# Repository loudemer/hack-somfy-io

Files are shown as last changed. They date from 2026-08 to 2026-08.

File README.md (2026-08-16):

# Hack télécommande Somfy pure IO

## Introduction
Home Assistant ne permet pas d'émuler les télécommandes Somfy IO. La solution est de passer par des boitiers Somfy type Tahoma, connexonn io ou équivalents qui représentent un budget non négligeable mais qui restent la meilleure solution lorsque l'on a plusieurs appareils Somfy car ils permettent en outre de récupérer l'état réel de chaque appareil. 
Lorsque l'on a un ou deux appareils Somfy IO et le reste en RTS comme moi, il devient interessant de hacker une telecommande Somfy IO pour la rendre pilotable par Home Assistant, ceci avec un faible budget mais à condition de savoir souder. 
Il existe déjà des [montages sur Youtube](https://www.youtube.com/watch?v=AbRFvk2iZs8&t=708s) qui expliquent comment faire. Le montage que je propose est dérivé de celui ci avec quelques améliorations sur un modèle de télécommande plus récent : Somfy Situo 1 Pure IO.

## Principe
La télécommande possède 3 boutons pour envoyer les 3 signaux : UP, MY, DOWN. Sur le circuit imprimé de la técommande, chaque bouton se présente sous forme d'un cercle entouré d'un anneau. l'appui sur un bouton met en contact le cercle et l'anneau, ce qui correspond à une mise à la masse de l'anneau. Ce dernier est normalement à 3,3v.

Il faut donc simplement mettre a la masse un des 3 anneaux pour déclencher une des commandes (UP,MY, DOWN). On peut le faire de plusieurs manières soit avec des relais commandés par HA ou plus simplement avec un circuit de type ESP32 ou Wemo D1 programmé avec ESPHome. C'est la solution proposée dans la vidéo citée précedemment qui utilise un ESP32. L'auteur a soudé un fil sur chacun des trois anneaux relié à 3 sorties GPIO de l'ESP32 et cela marche très bien. On effectue alors la commande à partir de HA.

Etant prudent, je voulais pouvoir toujours utiliser la télécommande au cas où il y aurait une panne sur HA. J'ai donc cherché les points correspondants aux 3 anneaux sur l'autre face du circuit imprimé pour y souder les 3 fils de commande et pouvoir ainsi garder les boutons de la télécommande opérationnels.
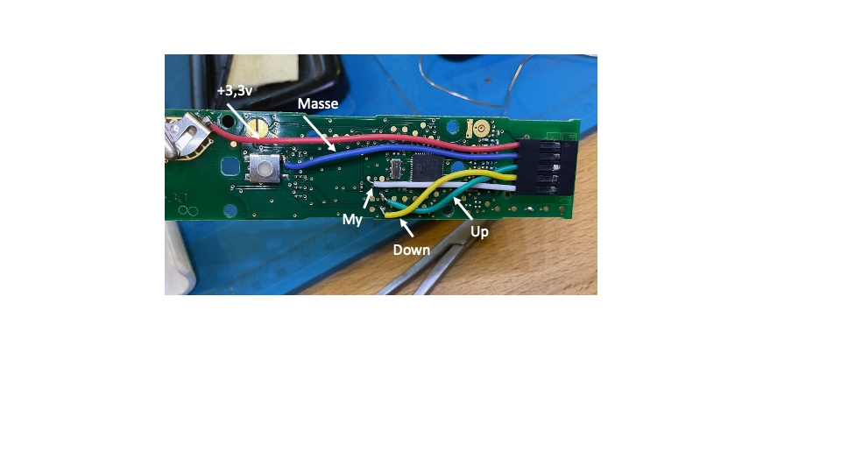
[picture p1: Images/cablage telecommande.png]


J'ai utilisé un Wemo D1 pour la commande, c'est largement suffisant. 

Il y a alors 2 problèmes à résoudre :
 1. lorsqu'on utilise les boutons de la télécommande, on met a la masse l'output du GPIO du Wemo, ce qui peut l'endommager. Il faut donc isoler la sortie du wemo en interposant un transistor selon le schéma suivant (une diode ne fonctionne pas).
 2. HA doit être informé de l'appui du bouton lorsqu'on utilise la télécommande, donc il faut renvoyer l'information sur 3 GPIO du wemo configurés en Input.

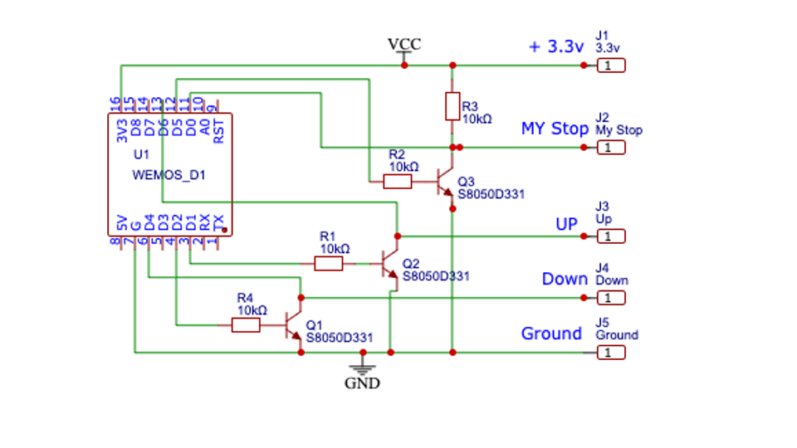
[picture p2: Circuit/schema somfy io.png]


L'alimentation de la télécommande se fait par le Wemo car la consommation est très basse. Il ne faut donc pas de pile dans la télécommande.

## Réalisation
Le montage du wemo et de son interface avec les transistors se fait au mieux sur un circuit imprimé. Un PCB est fourni en exemple pour sa réalisation. (format pdf dans le dossier PCB)
Les composants sont :
1. 3 transistors NPN S8050 ou BC547
2. 4 résistances 1/4 w 10K
3. 1 wemo D1

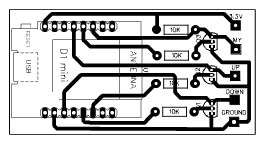
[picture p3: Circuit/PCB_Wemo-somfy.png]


Il faut souder 5 fils sur la télécommande +, -, UP, DOWN et MY comme indiqué sur la photo et les relier aux 5 sorties du circuit imprimé. 
On peut mettre une prise sur le cablage pour pouvoir détacher le circuit si besoin.

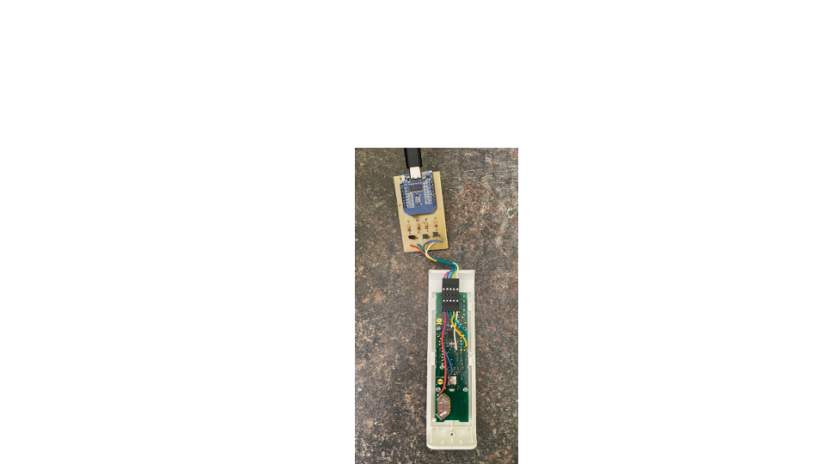
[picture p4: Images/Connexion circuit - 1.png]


Le circuit peut etre mis dans un boitier imprimé en 3D. Le fichier STL est joint.
Le boitier est solidarisé au dos de la télécommande avec un adhésif double face.

Icon

## Intégration ESPHome
Il faut flasher le wemo avec les paramètres suivants :
```yaml
# Board: Wemos D1 Mini (ESP8266)
# Hack télécommande Somfy Situo 1 IO Pure
#
# Sorties (simulation appuis boutons via transistors NPN S8050/BC547) :
#   GPIO5  (D1) → Résistance 10kΩ → Base transistor UP
#   GPIO4  (D2) → Résistance 10kΩ → Base transistor DOWN
#   GPIO14 (D5) → Résistance 10kΩ → Base transistor MY/Stop
#   Collecteur transistor → Pastille bouton cercle extérieur
#   Émetteur transistor → GND (pastille cercle intérieur)
#   inverted: false car le transistor NPN inverse déjà le signal
#
# Entrées (lecture appuis boutons physiques) :
#   Pastille → GPIO INPUT_PULLUP directement (sans diode)
#   Filtre anti-rebond 50ms uniquement
#   Flag global ha_command_active pour ignorer les échos des commandes HA
#   (au lieu de delayed_on 600ms qui nécessitait un appui trop long)
#
# Alimentation télécommande :
#   3V3 Wemos → Batterie + télécommande
#   GND Wemos → Batterie - télécommande

esphome:
  name: store-banne-io
  friendly_name: Store banne IO
  on_boot:
    priority: 600
    then:
      - switch.turn_off: store_banne_io_up
      - switch.turn_off: store_banne_io_down
      - switch.turn_off: store_banne_io_stop

esp8266:
  board: d1_mini

logger:

api:
  encryption:
    key: !secret store_banne_io__encryption_key

ota:
  - platform: esphome
    password: !secret store_banne_io__ota_password

wifi:
  min_auth_mode: WPA2
  ssid: !secret wifi_ssid
  password: !secret wifi_password
  ap:
    ssid: Store banne IO Fallback Hotspot
    password: "xxxxxxxxx"
  manual_ip:
    static_ip: 192.168.0.xx
    gateway: 192.168.0.1
    subnet: 255.255.255.0

# ---------------------------------------------------------------------------
# FLAG GLOBAL — Indique qu'une commande HA est en cours
# Permet aux binary_sensor d'ignorer les échos des commandes HA
# sans avoir besoin d'un delayed_on long
# ---------------------------------------------------------------------------

globals:
  - id: ha_command_active
    type: bool
    restore_value: false
    initial_value: 'false'

# ---------------------------------------------------------------------------
# SORTIES — Simulation appuis boutons via transistors NPN
# Le flag ha_command_active est mis à true pendant l'impulsion
# pour que les binary_sensor ignorent l'écho
# ---------------------------------------------------------------------------

switch:
  - platform: gpio
    id: store_banne_io_up
    name: "Bouton UP"
    entity_category: diagnostic
    icon: "mdi:arrow-up-bold"
    restore_mode: ALWAYS_OFF
    pin:
      number: GPIO5
      inverted: false
      mode:
        output: true
    interlock: [store_banne_io_stop, store_banne_io_down]
    on_turn_on:
      - globals.set:
          id: ha_command_active
          value: 'true'
      - delay: 300ms
      - switch.turn_off: store_banne_io_up
      - globals.set:
          id: ha_command_active
          value: 'false'

  - platform: gpio
    id: store_banne_io_down
    name: "Bouton DOWN"
    entity_category: diagnostic
    icon: "mdi:arrow-down-bold"
    restore_mode: ALWAYS_OFF
    pin:
      number: GPIO4
      inverted: false
      mode:
        output: true
    interlock: [store_banne_io_stop, store_banne_io_up]
    on_turn_on:
      - globals.set:
          id: ha_command_active
          value: 'true'
      - delay: 300ms
      - switch.turn_off: store_banne_io_down
      - globals.set:
          id: ha_command_active
          value: 'false'

  - platform: gpio
    id: store_banne_io_stop
    name: "Bouton Stop"
    entity_category: diagnostic
    icon: "mdi:square"
    restore_mode: ALWAYS_OFF
    pin:
      number: GPIO14
      inverted: false
      mode:
        output: true
    interlock: [store_banne_io_down, store_banne_io_up]
    on_turn_on:
      - globals.set:
          id: ha_command_active
          value: 'true'
      - delay: 300ms
      - switch.turn_off: store_banne_io_stop
      - globals.set:
          id: ha_command_active
          value: 'false'

# ---------------------------------------------------------------------------
# ENTREES — Lecture appuis boutons physiques
# Filtre anti-rebond 50ms uniquement — appui normal (~200ms) suffit
# Le flag ha_command_active filtre les échos des commandes HA
# La télécommande envoie directement la commande radio au store
# → on met à jour uniquement l'état HA via cover.template.publish
# ---------------------------------------------------------------------------

binary_sensor:
  - platform: gpio
    id: phys_up
    name: "Appui physique UP"
    entity_category: diagnostic
    pin:
      number: GPIO12 # D6
      mode:
        input: true
        pullup: true
      inverted: true
    filters:
      - delayed_on: 50ms
    on_press:
      then:
        - if:
            condition:
              lambda: 'return !id(ha_command_active);'
            then:
              - cover.template.publish:
                  id: store_banne_ouest
                  state: OPEN
                  current_operation: OPENING
              - logger.log: "Appui physique UP → état cover mis à jour OPEN"

  - platform: gpio
    id: phys_down
    name: "Appui physique DOWN"
    entity_category: diagnostic
    pin:
      number: GPIO2 # D4
      mode:
        input: true
        pullup: true
      inverted: true
    filters:
      - delayed_on: 50ms
    on_press:
      then:
        - if:
            condition:
              lambda: 'return !id(ha_command_active);'
            then:
              - cover.template.publish:
                  id: store_banne_ouest
                  state: CLOSED
                  current_operation: CLOSING
              - logger.log: "Appui physique DOWN → état cover mis à jour CLOSED"

  - platform: gpio
    id: phys_my
    name: "Appui physique Stop/My"
    entity_category: diagnostic
    pin:
      number: GPIO16 # D0
      mode:
        input: true
        # pas de pullup interne sur GPIO16 — résistance externe 10kΩ requise
      inverted: true
    filters:
      - delayed_on: 50ms
    on_press:
      then:
        - if:
            condition:
              lambda: 'return !id(ha_command_active);'
            then:
              - cover.template.publish:
                  id: store_banne_ouest
                  state: OPEN
                  current_operation: IDLE
              - logger.log: "Appui physique MY → état cover mis à jour IDLE"

# ---------------------------------------------------------------------------
# ENTITE COVER — cover: template + optimistic: true
# ---------------------------------------------------------------------------

cover:
  - platform: template
    id: store_banne_ouest
    name: "Store banne Ouest"
    optimistic: true
    icon: "mdi:awning-outline"
    device_class: awning                          # a modifier en fonction du device
    open_action:
      - switch.turn_on: store_banne_io_up
    close_action:
      - switch.turn_on: store_banne_io_down
    stop_action:
      - switch.turn_on: store_banne_io_stop
```
## Intégration dans HA
On a alors une entité cover qui permet de commander son appareil

## Limites 
On ne récupère pas l'état réel de son appareil. On récupère seulement la commande effectuée.

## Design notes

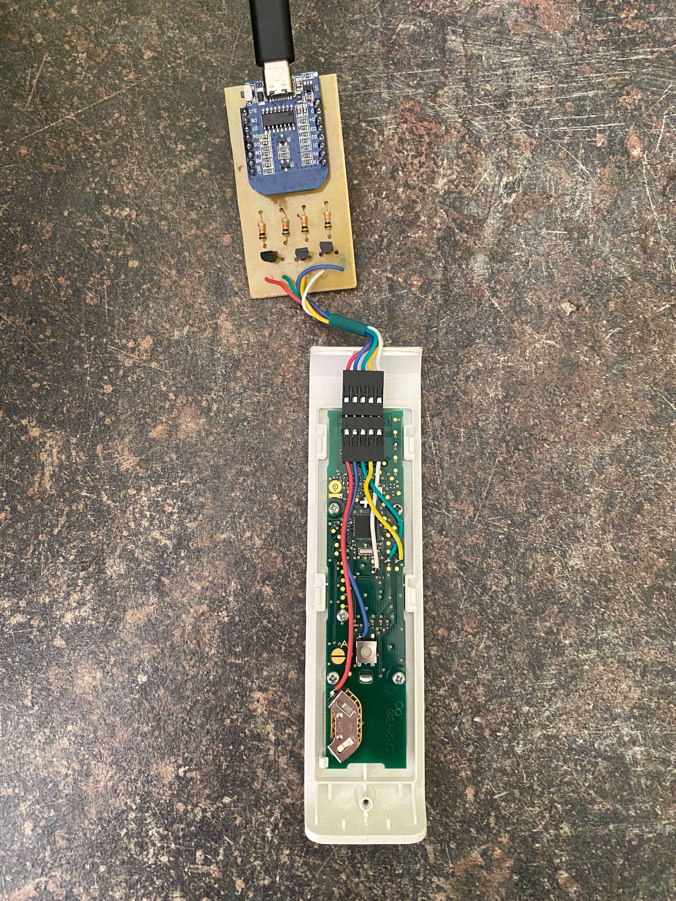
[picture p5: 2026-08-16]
Images/hack pure io - 1.jpeg

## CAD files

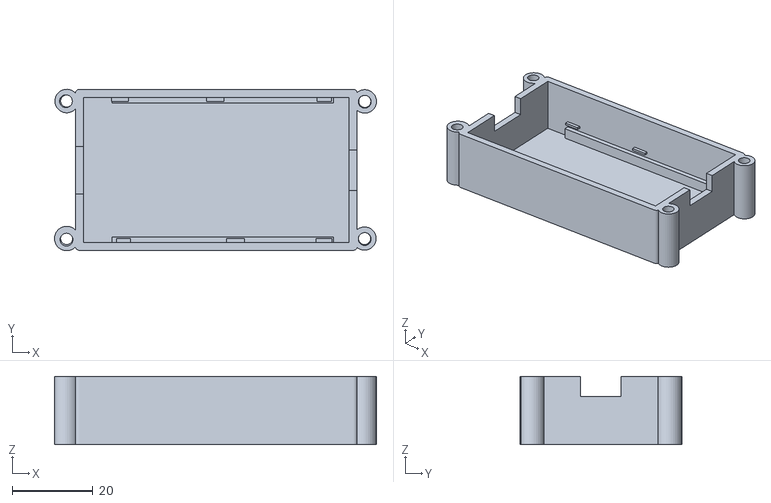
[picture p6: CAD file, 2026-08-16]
boitier/somfy io base.stl
80.0 x 40.1 x 17.0

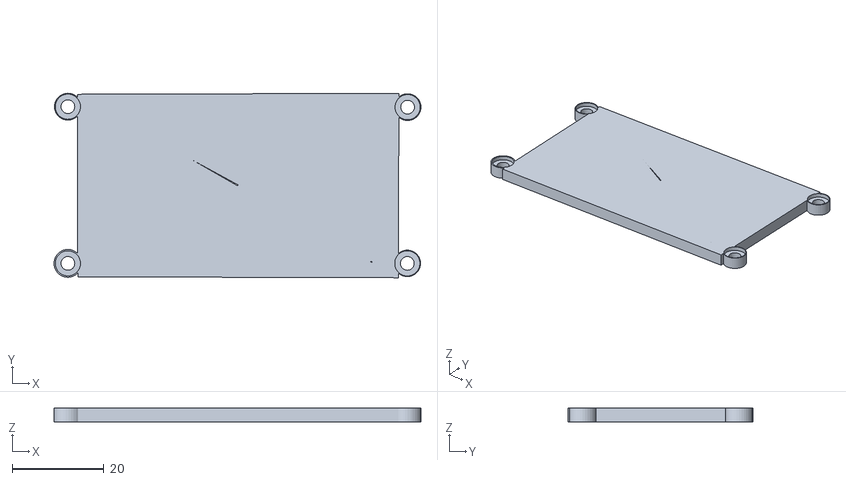
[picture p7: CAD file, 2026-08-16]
boitier/couvercle somfy io.stl
80.0 x 40.2 x 3.00

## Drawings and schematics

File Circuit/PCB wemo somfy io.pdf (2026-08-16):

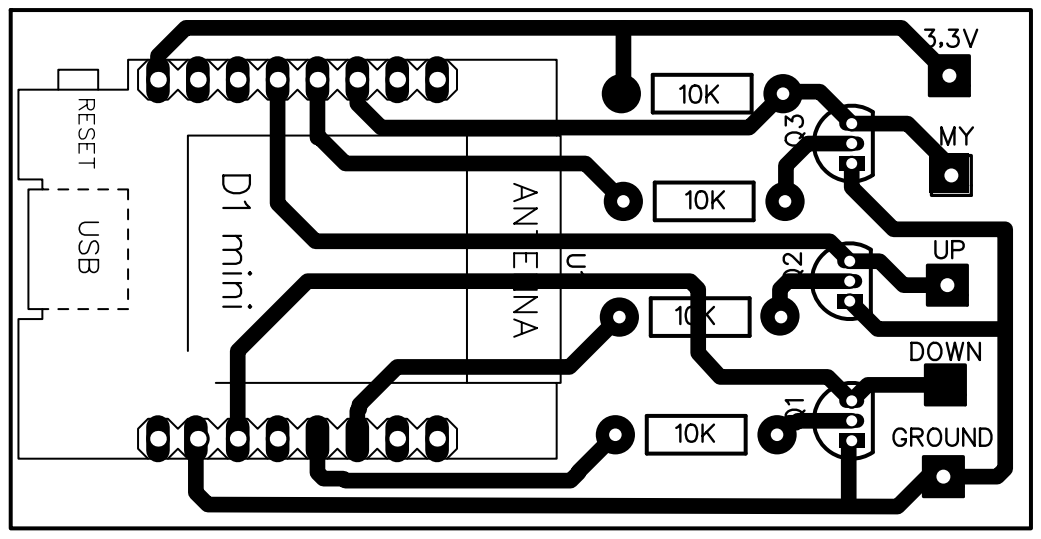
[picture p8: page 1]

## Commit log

2026-08-16 Hack somfy IO
    Hack somfy pure io situo 1 for home assistant
    [couvercle somfy io.stl, somfy io base.stl]
2026-08-16 Revise README for Somfy IO remote control integration
    Updated README to provide detailed instructions for hacking Somfy IO remote control for Home Assistant integration, including circuit diagrams and ESPHome configuration.
